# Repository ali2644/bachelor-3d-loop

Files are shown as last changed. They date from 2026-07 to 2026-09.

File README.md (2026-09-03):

# Automated R.E.P.P.R.I.N.T. - 3D-Druck-Qualitätsregelkreis

Dieses Repository automatisiert einen geschlossenen Versuchs- und Optimierungskreislauf für den FFF-3D-Druck. Ein Python-Orchestrator erzeugt aus Prozessparametern ein PrusaSlicer-Profil, überträgt den G-Code per PrusaLink, überwacht den Druck, lässt einen Niryo Ned2 das Bauteil in eine Qualitätsstation einlegen, liest `Ra` und `Rz` eines Mitutoyo SJ-220 aus und speichert Messwerte sowie Kamerabild. Ein separates Optimierer-Framework kann daraus den nächsten Parametersatz bestimmen.

> **Sicherheit:** Die Modi `robot-qs`, `full`, `experiment` und der bestätigte Optimierer-Hardwarelauf bewegen reale Hardware. Vor dem Start Arbeitsräume räumen, Not-Aus erreichbar halten und die mechanische Anordnung prüfen. Roboterbewegungen niemals blind wiederholen.

## Aktueller Stand

Der Stand dieses Übergabepakets basiert auf Branch `feature/optimizer-framework-integration`, Commit `29f11b9`.

| Bereich | Stand |
| --- | --- |
| Slicer, PrusaLink, Robotik, QS und Kamera | Im End-to-End-Orchestrator verbunden; reale Hardware hier nicht erneut getestet |
| Statischer Versuchsplan | Bis 100 Planzeilen, manueller Start-/Endbereich und Plan-Wiederverwendung |
| Optimierer | LHS/Random/Sobol-Warmstart sowie Bayesian, PSO, Differential Evolution, Random und Sobol; Hardwareadapter und persistenter Zustand vorhanden |
| Resume | Für vorgeschlagene, retry-fähige und terminal klassifizierte Läufe vorhanden; ein nach Prozessabbruch als `running` verbliebener Lauf besitzt noch keinen unterstützten CLI-Freigabepfad |
| Installation | Linux-orientiert; Dependency-Dateien sind derzeit unvollständig und werden in der Installationsanleitung erläutert |
| Tests | 129 Tests erfolgreich; ein veralteter Test importiert das nicht mehr vorhandene Modul `optimizer.bayesian_optimizer` |

## System in einem Satz

```text
Parameter -> Profil -> G-Code -> Druck -> Kamera -> Roboter -> Rauheitsmessung -> Speicherung -> nächster Parameter
```

Die Steueranwendung läuft auf dem Hauptrechner. Die FastAPI für SJ-220 und Kamera läuft auf dem Raspberry Pi. Drucker und Roboter werden über das lokale Netz angesprochen; das Messgerät hängt seriell, die Kamera per V4L2 am Raspberry Pi.

## Voraussetzungen in Kürze

- Linux auf Hauptrechner und Raspberry Pi; Python 3.10 oder neuer, mit 3.12.3 verifiziert.
- PrusaSlicer als ausführbare Datei auf dem Hauptrechner.
- Für Hardwarebetrieb: erreichbarer Prusa-Drucker mit PrusaLink, Niryo Ned2, Raspberry Pi 5, Mitutoyo SJ-220 und V4L2-Kamera.
- Auf dem Pi zusätzlich `ffmpeg` und `v4l2-ctl`.

## Schnellstart ohne Hardware

Alle folgenden Befehle werden im Repository-Root ausgeführt, sofern nicht anders angegeben.

```bash
python3.12 -m venv .venv
source .venv/bin/activate
python -m pip install --upgrade pip
python -m pip install -r 3d-automation/requirements.txt
python -m pip install numpy scipy scikit-learn
cd 3d-automation
export PYTHONPATH="$PWD/src"
python -m main --help
python -m optimizer.config config/optimizer_config.example.json --check-input-files
python -m optimizer.warm_start config/optimizer_config.example.json
```

Warum zusätzliche Pakete installiert werden müssen und welche Python-Version tatsächlich ableitbar ist, steht in [Installation](3d-automation/docs/03_installation.md).

Eine neue Simulation benötigt ein neues, noch nicht vorhandenes `paths.output_directory` in der Optimierer-JSON:

```bash
python -m optimizer.framework_runner \
  config/optimizer_config.simulation.json \
  --simulate \
  --new \
  --max-runs 6
```

Existiert das konfigurierte Ausgabeverzeichnis bereits, ist statt `--new` ein passender `--resume`-Aufruf erforderlich. Details: [Bedienung](3d-automation/docs/06_bedienung.md).

## Start mit Hardware - Kurzfassung

1. Auf dem Raspberry Pi die QS-/Kamera-API starten und `/health` sowie `/camera/health` prüfen.
2. Auf dem Hauptrechner `config/end_to_end.env.example` nach `config/end_to_end.env` kopieren, Zugangsdaten eintragen und die Datei in die Shell laden.
3. Zuerst `python -m main --mode preflight` ausführen.
4. Mechanik getrennt mit einem vorhandenen Bauteil prüfen.
5. Erst danach einen Einzelzyklus oder den bewachten Optimierer-Hardwarelauf starten.

```bash
cd 3d-automation
set -a
source config/end_to_end.env
set +a
export PYTHONPATH="$PWD/src"
python -m main --mode preflight
```

Der Optimierer besitzt zusätzliche Sicherheitsgates. Ein neues Experiment wird zunächst nur angelegt und geprüft:

```bash
cp config/optimizer_config.example.json \
  config/optimizer_config.hardware.local.json
# Danach Experimentname, sichere Grenzen und einen neuen Ausgabepfad eintragen.
python -m optimizer.hardware_cli \
  config/optimizer_config.hardware.local.json \
  --new \
  --preflight-only \
  --failure-result penalty
```

Die vorhandene `optimizer_config.example.json` ist ein Strukturbeispiel und keine automatische Freigabe für reale Hardware. Vor dem Aufruf muss die lokale Kopie kontrolliert editiert werden.

## Dokumentation

| Kapitel | Inhalt |
| --- | --- |
| [01 Systemüberblick](3d-automation/docs/01_systemueberblick.md) | Ziel, Geräteverteilung, Daten- und Kontrollfluss |
| [02 Repository und Architektur](3d-automation/docs/02_repository_und_architektur.md) | Verzeichnisse, Module, Klassen, Zustände und Schnittstellen |
| [03 Installation](3d-automation/docs/03_installation.md) | Einrichtung von Hauptrechner und Raspberry Pi |
| [04 Konfiguration](3d-automation/docs/04_konfiguration.md) | Umgebungsvariablen, CLI, JSON und Slicer-Profil |
| [05 Hardware-Setup](3d-automation/docs/05_hardware_setup.md) | Drucker, Roboter, SJ-220, Raspberry Pi, Kamera und QS |
| [06 Bedienung](3d-automation/docs/06_bedienung.md) | Befehle und vollständige Betriebschecklisten |
| [07 Versuche und Daten](3d-automation/docs/07_versuche_und_daten.md) | Pläne, IDs, CSV/JSON, Bilder, Logs und Resume |
| [08 Optimierer](3d-automation/docs/08_optimierer.md) | Warmstart, Strategien, Bayesian Optimization und Zustände |
| [09 Fehlerbehandlung](3d-automation/docs/09_fehlerbehandlung.md) | Diagnose, Retry, Penalty und manuelle Stopps |
| [10 Tests und Entwicklung](3d-automation/docs/10_tests_und_entwicklung.md) | Tests, Simulation, Erweiterung und Debugging |
| [11 API-Referenz](3d-automation/docs/11_api_referenz.md) | QS-/Kamera-Routen und Clientverhalten |
| [12 Übergabe und offene Punkte](3d-automation/docs/12_uebergabe_und_offene_punkte.md) | Reifegrad, Risiken, Schulden und nächste Schritte |

## Verbindliche Quellen

Bei Widersprüchen gilt in dieser Reihenfolge:

1. aktueller Produktionscode und zugehörige Tests,
2. aktuelle Konfigurationsdateien,
3. diese Übergabedokumentation,
4. ältere Meilenstein-Dokumente wie `OPTIMIZER_FRAMEWORK_STEP_*.md`.

Die älteren Schrittdateien bleiben als Entwicklungshistorie erhalten. Mehrere Aussagen darin sind inzwischen überholt; sie sind nicht die aktuelle Bedienungsanleitung.

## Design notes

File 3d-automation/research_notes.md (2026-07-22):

1. downloading and configuring prusaSlicer cli && first use of it 
https://www.accessiblestem.org/fabrication%20lab/prusa-slicer-advanced.html
2. Source of config file 
https://github.com/funkonaut/openSCAD_lessons/blob/main/3D_Printing/profiles/prusa_mini%2B/quality_supports_pla.ini

3. Slicer Manual 
https://manual.slic3r.org/advanced/command-line

4. sending g-codes to printer via network 
https://help.prusa3d.com/article/sending-g-codes-to-printer-via-network-prusa-connect-prusalink-octoprint_196761

5. for g-code understanding 
https://www.cnckitchen.com/blog/g-code-basics-for-3d-printing
https://howtomechatronics.com/tutorials/g-code-explained-list-of-most-important-g-code-commands/

6. Prusa Link API
https://pypi.org/project/PrusaLinkPy/

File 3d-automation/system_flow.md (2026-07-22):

Parameter → config.ini
Prusa CLI → G-Code
Upload via Prusa Link API
Druckstatus polling
FINISHED Signal
Robot fährt Greifsequenz
Übergabe an QS
RS232 Messung
Ergebnis zurück
Optimizer update

-------------------------------------------

Optimizer → Parameter
↓
Printer → Druck starten
↓
WAIT → FINISHED
↓
Robot → Teil entnehmen
↓
QS → messen
↓
Optimizer → neue Parameter
↓
LOOP

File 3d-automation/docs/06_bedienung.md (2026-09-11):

# 06 – Bedienung

Diese Anleitung beschreibt die Bedienung des Systems aus Sicht der Person, die
Versuche plant, startet, überwacht, fortsetzt und die Ergebnisse weitergibt.
Für die Bedienung ist kein Verständnis jeder Python-Klasse erforderlich.

## 1. Die zwei Programmeinstiege

Es gibt zwei getrennte Bedienwege:

| Einstieg | Zweck | Ergebnisverwaltung |
|---|---|---|
| `python -m main` | Preflight, Roboter-QS-Test, einzelner Druck oder vorgegebener CSV-Versuchsplan | ausdrücklich angegebene `--results-csv` |
| `python -m optimizer.hardware_cli` | Optimierer mit Warmstart, BO, PSO, DE, Random oder Sobol | eigener Experimentordner aus der Optimierer-JSON |

`main` und das Optimierer-Framework sollen nicht gleichzeitig auf die Anlage
zugreifen.

## 2. Sicherheits- und Datenregeln

1. Vor Hardwarebefehlen Druckbett, Roboterbereich, Zuführung und Messstation
   prüfen.
2. Es darf immer nur ein steuernder Prozess laufen.
3. Ein neuer Versuch erhält einen neuen Ergebnisnamen beziehungsweise einen
   neuen `output_directory`.
4. Eine begonnene Optimierer-Konfiguration wird nicht verändert. Änderungen an
   STL, Profil, Grenzen, Zielfunktion oder Strategie erfordern ein neues
   Experiment.
5. `--new` bedeutet wirklich neues Experiment. `--resume` öffnet ein
   vorhandenes Experiment.
6. Einen physischen Optimiererlauf niemals ohne vorherigen erfolgreichen
   Preflight starten.
7. Bei einem unklaren Roboter- oder Anlagenzustand zuerst die Anlage prüfen und
   erst danach einen Wiederanlauf bestätigen.

## 3. Einrichtung auf einem neuen Benutzerkonto

### 3.1 Projektstand laden

Im bereits geklonten Repository:

```bash
git fetch origin
git switch feature/optimizer-framework-integration
git pull --ff-only
git status -sb
```

Erwartet wird ein sauberer Arbeitsbaum. Falls der Branch lokal noch nicht
existiert:

```bash
git switch --track origin/feature/optimizer-framework-integration
```

### 3.2 Python-Umgebung

Vom Repository-Ordner `bachelor-3d-loop` aus:

```bash
python3 -m venv .venv
source .venv/bin/activate
python -m pip install --upgrade pip
python -m pip install -r 3d-automation/requirements.txt
cd 3d-automation
```

Vor jedem neuen Terminal:

```bash
cd ~/Projects/bachelor-3d-loop
source .venv/bin/activate
cd 3d-automation
export PYTHONPATH="$PWD/src"
```

Der Hardwarebetrieb ist für den Linux-Laborrechner vorgesehen. Auf einem
Windows-Laptop können Konfiguration, Simulation und viele Tests betrachtet
werden; Robotik, serielle QS-Anbindung und Laborpfade sind dort nicht
betriebsbereit.

### 3.3 Lokale Umgebungsdatei

Einmalig:

```bash
cp config/end_to_end.env.example config/end_to_end.env
chmod 600 config/end_to_end.env
nano config/end_to_end.env
```

Mindestens zu prüfen:

| Variable | Bedeutung |
|---|---|
| `PRINTER_IP` | IP-Adresse des PrusaLink-Druckers |
| `PRUSALINK_API_KEY` | persönlicher beziehungsweise freigegebener API-Key |
| `ROBOT_IP` | IP-Adresse des Niryo-Roboters |
| `QS_BASE_URL` | Basis-URL der QS-API auf dem Raspberry Pi |
| `CAMERA_BASE_URL` | Kamera-API; normalerweise gleich `QS_BASE_URL` |
| `PRUSASLICER_PATH` | lokaler Pfad zur PrusaSlicer-AppImage |
| `REMOTE_GCODE_PATH` | Zielpfad auf dem Drucker |
| `PRINT_POLL_SECONDS` | Abstand zwischen Druckerstatusabfragen |
| `PRINT_START_TIMEOUT_SECONDS` | maximale Zeit bis der neue Druck aktiv ist |
| `PRINT_TIMEOUT_SECONDS` | maximale Druckdauer |
| `MAX_STATUS_ERRORS` | erlaubte aufeinanderfolgende Statusfehler |
| `PART_COOLING_SECONDS` | Abkühlzeit vor der Roboterbewegung |

Die Datei in die aktuelle Shell laden:

```bash
set -a
source config/end_to_end.env
set +a
```

`config/end_to_end.env` enthält Zugangsdaten und wird nicht committed.

### 3.4 Offline-Abnahme

```bash
PYTHONPATH=src python -m unittest discover -s tests -v
```

Alle Tests müssen mit `OK` enden. Die Tests verwenden simulierte Dienste und
starten weder Drucker noch Roboter.

## 4. Eingabedateien auswählen

Vor einem Versuch müssen vier Arten von Eingaben bewusst gewählt werden:

| Eingabe | Beispiel | Regel |
|---|---|---|
| STL-Modell | `data/models/15x15_V2_rounded.stl` | vor jedem neuen Experiment prüfen |
| Slicer-Basisprofil | `config/slicer_profile.ini` | muss ein vollständiges, funktionierendes Profil sein |
| Ergebnisziel für `main` | `data/results/validation_2026-09-08.csv` | neuer Dateiname für neue Reihe |
| Optimierer-Konfiguration | `config/optimizer_config.hardware.json` | enthält zusätzlich Strategie und Experimentordner |

Absolute und relative Pfade in einer Optimierer-JSON sind erlaubt. Relative
Pfade werden relativ zum Ordner der JSON-Datei aufgelöst.

## 5. Bedienung von `main`

### 5.1 Warum `--results-csv` immer angegeben wird

`--results-csv` ist jetzt ein Pflichtargument. Dadurch kann nicht mehr
unbemerkt eine alte Standard-CSV mit einem anderen Spaltenschema verwendet
werden. Eine vorhandene Datei wird beim Programmstart geprüft, also vor Druck
und Roboterbewegung.

Regel:

- neue Versuchsreihe: neuer CSV-Dateiname;
- Fortsetzung derselben Reihe: dieselbe kompatible CSV;
- alte oder anders aufgebaute CSV: nicht überschreiben, sondern neuen Namen
  wählen oder die alte Datei separat archivieren.

Nur das unmittelbar vorherige Programmschema ohne die neue Spalte
`print_time_seconds` wird verlustfrei ergänzt. Andere Fremd- oder Altschemata
werden weiterhin abgelehnt.

### 5.2 Preflight

```bash
PYTHONPATH=src python -m main \
  --mode preflight \
  --stl data/models/15x15_V2_rounded.stl \
  --profile config/slicer_profile.ini \
  --results-csv data/results/preflight_check.csv
```

Der Preflight prüft Dateien und erreichbare Dienste. Er startet keinen Druck
und bewegt den Roboter nicht. Die angegebene Ergebnisdatei wird durch einen
erfolgreichen Preflight nicht beschrieben; sie ist trotzdem ausdrücklich
angegeben, damit jeder `main`-Aufruf dieselbe eindeutige Form hat.

### 5.3 Nur Roboter und QS mit vorhandenem Bauteil

```bash
PYTHONPATH=src python -m main \
  --mode robot-qs \
  --stl data/models/15x15_V2_rounded.stl \
  --profile config/slicer_profile.ini \
  --results-csv data/results/robot_qs_2026-09-08.csv
```

Das Bauteil muss vorher an der eingelernten Position liegen. Es wird nicht
gesliced oder gedruckt. Robotertransport, QS-Messung und Ergebnisaufzeichnung
werden ausgeführt.

### 5.4 Ein vollständiger Zyklus mit Profilwerten

```bash
PYTHONPATH=src python -m main \
  --mode full \
  --stl data/models/15x15_V2_rounded.stl \
  --profile config/slicer_profile.ini \
  --generated-profiles-dir data/generated_profiles \
  --gcode data/gcode/single_cycle.gcode \
  --results-csv data/results/single_cycle_2026-09-08.csv
```

Ohne Parameterargumente werden die sechs Werte aus dem Basisprofil gelesen.

### 5.5 Ein vollständiger Zyklus mit allen Parameterargumenten

```bash
PYTHONPATH=src python -m main \
  --mode full \
  --stl data/models/15x15_V2_rounded.stl \
  --profile config/slicer_profile.ini \
  --generated-profiles-dir data/generated_profiles \
  --gcode data/gcode/single_cycle_all_arguments.gcode \
  --results-csv data/results/single_cycle_all_arguments.csv \
  --top-solid-layers 5 \
  --print-speed 70.0 \
  --extrusion-width 0.42 \
  --extrusion-multiplier 1.10 \
  --temperature 225 \
  --fan-speed 60
```

Diese Parameter gelten nur für einen einzelnen `full`- oder `robot-qs`-Aufruf.
Im Modus `experiment` kommen die Parameter aus dem CSV-Plan; dort werden
Parameterargumente abgelehnt.

### 5.6 Neuen CSV-Versuchsplan erzeugen und ausführen

Das folgende Beispiel erzeugt reproduzierbar einen 100-Zeilen-Plan und führt
die Einträge 1 bis einschließlich 20 aus:

```bash
mkdir -p data/results

RESULTS_CSV="data/results/experiment_$(date +%Y%m%d_%H%M%S).csv"

printf '%s\n' "$RESULTS_CSV" \
  > data/results/active_experiment_results.txt

PYTHONPATH=src python -m main \
  --mode experiment \
  --stl data/models/15x15_V2_rounded.stl \
  --profile config/slicer_profile.ini \
  --generated-profiles-dir data/generated_profiles \
  --gcode data/gcode/experiment.gcode \
  --results-csv "$RESULTS_CSV" \
  --experiment-plan config/experiment_plans/experiment_plan_100.csv \
  --experiment-start-cycle 1 \
  --experiment-cycles 100 \
  --experiment-plan-seed 42
```

`--experiment-cycles` ist die Nummer des letzten Eintrags, nicht die Anzahl ab
dem Start. Beispiel: Start 49 und Ende 100 führen 52 Zyklen aus.

Ohne `--reuse-experiment-plan` wird ein neuer Plan erzeugt. Der vorherige Plan
wird im Archivordner gesichert.

### 5.7 Unterbrochenen CSV-Versuchsplan fortsetzen

```bash
RESULTS_CSV="$(cat data/results/active_experiment_results.txt)"

PYTHONPATH=src python -m main \
  --mode experiment \
  --stl data/models/15x15_V2_rounded.stl \
  --profile config/slicer_profile.ini \
  --generated-profiles-dir data/generated_profiles \
  --gcode data/gcode/experiment.gcode \
  --results-csv "$RESULTS_CSV" \
  --experiment-plan config/experiment_plans/experiment_plan_100.csv \
  --experiment-start-cycle 38 \
  --experiment-cycles 100 \
  --reuse-experiment-plan
```

Beim Fortsetzen darf `--experiment-plan-seed` nicht zusätzlich angegeben
werden. Sonst wäre unklar, ob der bestehende oder ein neuer Plan gemeint ist.

## 5.8 Ergebnisse einer `main`-Versuchsreihe gemeinsam speichern

Für jede neue Versuchsreihe wird ein eigener Ordner angelegt. Darin werden folgende Dateien gespeichert:

- verwendetes STL-Modell,
- verwendetes Slicer-Basisprofil,
- Parameterplan,
- generierte Slicer-Profile,
- erzeugte G-Code-Dateien,
- Kamerabilder,
- Ergebnis-CSV,
- vollständige Terminalausgabe als Logdatei.

### 5.8.1 Neue Versuchsreihe starten

> Dieser Block darf nur für eine neue Versuchsreihe verwendet werden.  
> Für die Fortsetzung einer unterbrochenen Reihe muss der Befehl aus dem nächsten Abschnitt verwendet werden.

Den folgenden Block vollständig kopieren und im Projektordner ausführen:

```bash
set -o pipefail

mkdir -p data/experiments

RUN_DIR="data/experiments/main_$(date +%Y%m%d_%H%M%S_%N)"

mkdir -p "$RUN_DIR"/{input,generated_profiles,gcode,images,logs}

cp data/models/15x15_V2_rounded.stl \
  "$RUN_DIR/input/model.stl"

cp config/slicer_profile.ini \
  "$RUN_DIR/input/base_profile.ini"

printf '%s\n' "$RUN_DIR" \
  > data/experiments/active_main_experiment.txt

CAMERA_DOWNLOAD_DIR="$RUN_DIR/images" \
PYTHONPATH=src python -m main \
  --mode experiment \
  --stl "$RUN_DIR/input/model.stl" \
  --profile "$RUN_DIR/input/base_profile.ini" \
  --generated-profiles-dir "$RUN_DIR/generated_profiles" \
  --gcode "$RUN_DIR/gcode/output.gcode" \
  --results-csv "$RUN_DIR/results.csv" \
  --experiment-plan "$RUN_DIR/experiment_plan_100.csv" \
  --experiment-start-cycle 1 \
  --experiment-cycles 100 \
  --experiment-plan-seed 42 \
  2>&1 | tee "$RUN_DIR/logs/main.log"
```

Der Zeitstempel sorgt dafür, dass jede Versuchsreihe einen neuen eindeutigen Ordner erhält, zum Beispiel:

```text
data/experiments/main_20260907_143215_382019475/
```

Die Datei

```text
data/experiments/active_main_experiment.txt
```

enthält den Pfad der aktuell laufenden Versuchsreihe. Dadurch muss sich der Bediener den erzeugten Zeitstempel nicht merken.

Die Ergebnisse werden folgendermaßen abgelegt:

```text
data/experiments/main_20260907_143215_382019475/
├── input/
│   ├── model.stl
│   └── base_profile.ini
├── experiment_plan_100.csv
├── generated_profiles/
│   ├── cycle_001_profile.ini
│   ├── cycle_002_profile.ini
│   └── ...
├── gcode/
│   ├── cycle_001.gcode
│   ├── cycle_002.gcode
│   └── ...
├── images/
│   ├── <cycle-id>.jpg
│   └── ...
├── logs/
│   └── main.log
└── results.csv
```

Bedeutung der wichtigsten Dateien:

| Datei oder Ordner | Inhalt |
|---|---|
| `input/model.stl` | Kopie des verwendeten Druckmodells |
| `input/base_profile.ini` | Kopie des verwendeten Slicer-Basisprofils |
| `experiment_plan_100.csv` | Parameter aller 100 geplanten Zyklen |
| `generated_profiles/` | Für jeden Zyklus erzeugtes Slicer-Profil |
| `gcode/` | Für jeden Zyklus erzeugter G-Code |
| `images/` | Von der Kamera aufgenommene Bauteilbilder |
| `results.csv` | Ergebnisse und Zustände der ausgeführten Zyklen |
| `logs/main.log` | Vollständige Terminalausgabe der Versuchsreihe |

### 5.8.2 Unterbrochene Versuchsreihe fortsetzen

Beim Fortsetzen darf kein neuer Versuchsordner und kein neuer Parameterplan erzeugt werden.

Zuerst muss bestimmt werden, welcher Zyklus als Nächstes ausgeführt werden soll.

Beispiel:

- Zyklus 37 wurde erfolgreich abgeschlossen.
- Die Fortsetzung beginnt deshalb bei Zyklus 38.
- `--experiment-cycles 100` bedeutet, dass bis einschließlich Zyklus 100 ausgeführt wird.

Den folgenden Block vollständig kopieren und ausführen:

```bash
set -o pipefail

RUN_DIR="$(cat data/experiments/active_main_experiment.txt)"

CAMERA_DOWNLOAD_DIR="$RUN_DIR/images" \
PYTHONPATH=src python -m main \
  --mode experiment \
  --stl "$RUN_DIR/input/model.stl" \
  --profile "$RUN_DIR/input/base_profile.ini" \
  --generated-profiles-dir "$RUN_DIR/generated_profiles" \
  --gcode "$RUN_DIR/gcode/output.gcode" \
  --results-csv "$RUN_DIR/results.csv" \
  --experiment-plan "$RUN_DIR/experiment_plan_100.csv" \
  --experiment-start-cycle 38 \
  --experiment-cycles 100 \
  --reuse-experiment-plan \
  2>&1 | tee -a "$RUN_DIR/logs/main.log"
```

Die Zahl hinter `--experiment-start-cycle` muss durch die Nummer des nächsten auszuführenden Zyklus ersetzt werden.

Beispiele:

| Letzter vollständig abgeschlossener Zyklus | Nächster Startwert |
|---:|---:|
| 10 | `--experiment-start-cycle 11` |
| 37 | `--experiment-start-cycle 38` |
| 60 | `--experiment-start-cycle 61` |
| 99 | `--experiment-start-cycle 100` |

Beim Fortsetzen bewirkt `--reuse-experiment-plan`, dass der vorhandene Parameterplan unverändert geladen wird.

Außerdem werden weiterhin dieselben Ablagen verwendet:

- dieselbe `results.csv`,
- derselbe Bilderordner,
- derselbe G-Code-Ordner,
- derselbe Profilordner,
- dieselbe Logdatei.

`tee -a` hängt die neue Terminalausgabe an die vorhandene Logdatei an. Die vorherige Ausgabe wird dadurch nicht überschrieben.

### 5.8.3 Wichtige Regeln beim Fortsetzen

Beim Fortsetzen dürfen folgende Bestandteile nicht verwendet werden:

```text
$(date ...)
--experiment-plan-seed
```

Ein neuer Zeitstempel würde einen neuen Ordner erzeugen. Ein neuer Seed würde einen neuen Parameterplan erzeugen.

Zum Fortsetzen werden stattdessen immer verwendet:

```text
data/experiments/active_main_experiment.txt
--reuse-experiment-plan
```

### 5.8.4 Aktuellen Versuchsordner anzeigen

```bash
cat data/experiments/active_main_experiment.txt
```

### 5.8.5 Gespeicherte Dateien anzeigen

```bash
RUN_DIR="$(cat data/experiments/active_main_experiment.txt)"

find "$RUN_DIR" -maxdepth 2 -type f | sort
```

### 5.8.6 Hinweis zur Ordneraufteilung

Dieser Ablauf erstellt einen gemeinsamen Ordner für eine vollständige Versuchsreihe.

Die einzelnen Zyklen erhalten darin jeweils:

- ein eigenes generiertes Slicer-Profil,
- eine eigene G-Code-Datei,
- ein eigenes Kamerabild,
- eine eigene Zeile in `results.csv`.

Es wird nicht für jeden einzelnen Zyklus ein separater Hauptordner erstellt.

### 5.9 Alle `main`-Argumente

| Argument | Wirkung |
|---|---|
| `--mode` | `preflight`, `robot-qs`, `full` oder `experiment` |
| `--stl` | verwendetes Modell |
| `--profile` | unverändertes Basisprofil |
| `--generated-profiles-dir` | Ablage der erzeugten Profile |
| `--gcode` | G-Code-Ziel; bei Experimenten wird dessen Ordner verwendet |
| `--results-csv` | Pflichtziel für Zyklusergebnisse |
| `--experiment-plan` | CSV-Datei mit 100 Parametersätzen |
| `--experiment-start-cycle` | erster Planindex, inklusive |
| `--experiment-cycles` | letzter Planindex, inklusive |
| `--reuse-experiment-plan` | vorhandenen Plan beibehalten |
| `--experiment-plan-seed` | Seed für einen reproduzierbaren neuen Plan |
| sechs Parameterargumente | Einzelzykluswerte; im Experimentmodus verboten |

## 6. Optimierer-Konfiguration

### 6.1 Grundstruktur

```json
{
  "schema_version": 1,
  "experiment_name": "surface_roughness_example_001",
  "total_runs": 100,
  "seed": 42,
  "objective": "Ra_um + 0.1 * print_time_minutes",
  "warm_start": {
    "method": "lhs",
    "sample_count": 10
  },
  "strategy": {
    "name": "bayesian",
    "options": {
      "acquisition": "ei",
      "candidate_count": 4096,
      "n_restarts_optimizer": 5
    }
  },
  "parameters": [
    {"name": "print_speed", "lower": 50, "upper": 90},
    {"name": "extrusion_width", "lower": 0.38, "upper": 0.50},
    {"name": "extrusion_multiplier", "lower": 1.05, "upper": 1.20},
    {"name": "temperature", "lower": 215, "upper": 235},
    {"name": "fan_speed", "lower": 30, "upper": 80}
  ],
  "fixed_parameters": {
    "top_solid_layers": 5
  },
  "paths": {
    "stl": "../data/models/15x15_V2_rounded.stl",
    "base_profile": "slicer_profile.ini",
    "output_directory": "../data/optimization_runs/example_001",
    "history_csvs": []
  }
}
```

### 6.2 Felder

| Feld | Bedeutung |
|---|---|
| `schema_version` | Formatversion; aktuell `1` |
| `experiment_name` | eindeutiger lesbarer Name |
| `total_runs` | Zahl abgeschlossener Parametersätze, nicht physischer Versuche |
| `seed` | reproduzierbare Zufallsfolge |
| `objective` | zu minimierende Messgröße oder Rechenformel |
| `warm_start.method` | `lhs`, `random` oder `sobol` |
| `warm_start.sample_count` | Zahl der Startpunkte; bei Batchstrategien zugleich Batchgröße |
| `strategy.name` | `bayesian`, `pso`, `differential_evolution`, `random` oder `sobol` |
| `strategy.options` | Optionen der gewählten Strategie |
| `parameters` | variable Parameter und frei gewählte Grenzen |
| `fixed_parameters` | nicht optimierte Parameter |
| `paths.output_directory` | ausschließlich für dieses Experiment |
| `paths.history_csvs` | reserviert; aktuell immer `[]`, Import noch nicht implementiert |

Jeder der sechs Prozessparameter muss genau einmal vorkommen: entweder variabel
in `parameters` oder fest in `fixed_parameters`.

### 6.3 Frei wählbare Grenzen und Top-Layer

`top_solid_layers` bleibt für den aktuellen Versuch fest auf 5:

```json
"fixed_parameters": {"top_solid_layers": 5}
```

Für einen späteren Versuch kann es stattdessen optimiert werden:

```json
"parameters": [
  {"name": "top_solid_layers", "lower": 3, "upper": 7}
],
"fixed_parameters": {
  "print_speed": 70,
  "extrusion_width": 0.42,
  "extrusion_multiplier": 1.10,
  "temperature": 225,
  "fan_speed": 60
}
```

Formale Mindestregeln: Geschwindigkeiten, Breiten und Multiplikator sind größer
als null; Temperatur und Top-Layer sind nichtnegative ganze Zahlen; Lüfter ist
eine ganze Zahl von 0 bis 100; bei Variablen gilt `lower < upper`. Formal
gültige extreme Grenzen sind nicht automatisch physikalisch sicher.

### 6.4 Zielfunktion

`objective` ist eine sichere arithmetische Formel. Verfügbare Größen:

| Name | Einheit | Bedeutung |
|---|---:|---|
| `Ra_um` | µm | gemessener Ra-Wert |
| `Rz_um` | µm | gemessener Rz-Wert |
| `print_time` | s | beobachtete Druckzeit |
| `print_time_seconds` | s | eindeutiger Alias für `print_time` |
| `print_time_minutes` | min | Druckzeit geteilt durch 60 |

Erlaubt sind Zahlen, Klammern und `+`, `-`, `*`, `/`, `**`. Nicht erlaubt
sind Funktionsaufrufe, Vergleiche, Imports oder beliebige Python-Ausdrücke.

Beispiele:

```json
"objective": "Ra_um"
```

```json
"objective": "Ra_um + 0.1 * print_time_minutes"
```

```json
"objective": "5 + print_time_minutes * Ra_um + Rz_um"
```

Die Gewichte bestimmen die fachliche Bedeutung. Sekundenwerte sind numerisch
viel größer als Rauheitswerte; deshalb ist meist `print_time_minutes` oder ein
kleiner Faktor sinnvoll.

`print_time` wird ab dem Warten auf den nach dem Upload gestarteten Druck bis
zum beobachteten Zustand `FINISHED` gemessen. Slicing, Kamera, Abkühlen,
Roboterbewegung und QS-Messung gehören nicht dazu. `duration_seconds` in
`hardware_cycles.csv` ist dagegen die Gesamtdauer des gesamten Zyklus.

Bei einem Parametersatz, der zweimal fehlschlägt, wird die Formel nicht mit
erfundenen Ra-, Rz- oder Zeitwerten ausgewertet. Im Modus `penalty` wird direkt
`objective_value = 100.0` gespeichert. Deshalb muss 100 auf der Skala der
gewählten Formel tatsächlich ein schlechter Wert sein. Andernfalls ist für
dieses Experiment `ignore` die fachlich sichere Wahl.

### 6.5 Strategiebedingungen

- Bayesian: nach dem Warmstart jeweils ein neuer Vorschlag.
- PSO, DE, Random und Sobol: Vorschläge in vollständigen Batches der Größe
  `warm_start.sample_count`.
- Bei den Batchstrategien muss `total_runs - sample_count` ohne Rest durch
  `sample_count` teilbar sein.
- PSO benötigt mindestens 2 Startpunkte, DE mindestens 4.

## 7. Optimierer offline prüfen

### 7.1 JSON und Eingabedateien prüfen

```bash
PYTHONPATH=src python -m optimizer.config \
  config/optimizer_config.hardware.json \
  --check-input-files
```

Ohne `--check-input-files` wird nur Struktur und Inhalt der JSON geprüft.

### 7.2 Warmstartpunkte anzeigen

```bash
PYTHONPATH=src python -m optimizer.warm_start \
  config/optimizer_config.hardware.json
```

Das erzeugt keine Hardwarebewegung und legt noch kein Experiment an.

### 7.3 Neue Simulation

Vorher in der Simulations-JSON einen noch nicht vorhandenen
`output_directory` wählen:

```bash
PYTHONPATH=src python -m optimizer.framework_runner \
  config/optimizer_config.simulation.json \
  --new \
  --simulate \
  --max-runs 3
```

### 7.4 Simulation fortsetzen

```bash
PYTHONPATH=src python -m optimizer.framework_runner \
  config/optimizer_config.simulation.json \
  --resume \
  --simulate \
  --from-run 4 \
  --max-runs 2
```

`--retry-failed` wird nur verwendet, wenn der gespeicherte nächste Run den
Status `retryable_failed` besitzt:

```bash
PYTHONPATH=src python -m optimizer.framework_runner \
  config/optimizer_config.simulation.json \
  --resume \
  --simulate \
  --from-run 4 \
  --retry-failed \
  --max-runs 1
```

## 8. Neues Optimierer-Hardwareexperiment

### 8.1 Konfiguration kopieren

```bash
cp config/optimizer_config.example.json \
  config/optimizer_config.hardware.json
nano config/optimizer_config.hardware.json
```

Prüfen:

- neuer `experiment_name`;
- neuer, noch nicht vorhandener `output_directory`;
- richtige STL;
- richtiges Basisprofil;
- gewünschte Grenzen und feste Parameter;
- gewünschte Zielfunktion;
- Strategie, Warmstart und Gesamtzahl;
- `history_csvs` ist `[]`.

### 8.2 Fehlerergebnis einmalig wählen und Preflight ausführen

Penalty soll in den Optimierer eingehen:

```bash
PYTHONPATH=src python -m optimizer.hardware_cli \
  config/optimizer_config.hardware.json \
  --new \
  --failure-result penalty \
  --preflight-only
```

Fehlerhafter Parametersatz soll nicht als Optimiererbeobachtung eingehen:

```bash
PYTHONPATH=src python -m optimizer.hardware_cli \
  config/optimizer_config.hardware.json \
  --new \
  --failure-result ignore \
  --preflight-only
```

Die Wahl wird in `run_state.json` gespeichert und darf innerhalb des
Experiments nicht gewechselt werden.

### 8.3 Genau einen Parametersatz ausführen

```bash
PYTHONPATH=src python -m optimizer.hardware_cli \
  config/optimizer_config.hardware.json \
  --resume \
  --from-run 1 \
  --max-runs 1 \
  --confirm-hardware
```

Ohne `--max-runs` ist 1 der Standard. Ohne `--confirm-hardware` wird kein
physischer Optimiererzyklus gestartet.

### 8.4 Mehrere Parametersätze automatisch ausführen

Beispiel für 12 abgeschlossene Parametersätze:

```bash
PYTHONPATH=src python -m optimizer.hardware_cli \
  config/optimizer_config.hardware.json \
  --resume \
  --from-run 1 \
  --max-runs 12 \
  --automatic-retry \
  --confirm-hardware
```

`--max-runs 12` zählt Parametersätze, nicht physische Drucke. Ein automatisch
wiederholter Fehlversuch kann also zusätzliche physische Zyklen verursachen.
Vor jedem Versuch wird ein Preflight-Nachweis erzeugt oder geprüft.

## 9. Fehler- und Wiederanlaufregeln

### 9.1 Normaler vergleichbarer Fehler

Bei einem vergleichbaren Druck-/Status- oder Messfehler:

1. Versuch 1 wird mit Fehler archiviert.
2. Mit `--automatic-retry` werden dieselben Parameter genau einmal wiederholt.
3. Bei Erfolg werden echte Werte gespeichert.
4. Bei erneutem Fehler wird der Parametersatz als `penalty` oder
   `ignored_failure` abgeschlossen.
5. Ein dritter automatischer Versuch ist nicht erlaubt.

Ohne automatischen Modus wird der erste Fehler bewusst sichtbar. Danach:

```bash
PYTHONPATH=src python -m optimizer.hardware_cli \
  config/optimizer_config.hardware.json \
  --resume \
  --from-run X \
  --retry-failed \
  --preflight-only
```

Nach erfolgreichem Preflight:

```bash
PYTHONPATH=src python -m optimizer.hardware_cli \
  config/optimizer_config.hardware.json \
  --resume \
  --from-run X \
  --max-runs 1 \
  --confirm-hardware
```

### 9.2 Preflight-Fehler

Ein Preflight-Fehler verbraucht keinen physischen Versuch. Ursache beheben und
denselben Run erneut preflighten:

```bash
PYTHONPATH=src python -m optimizer.hardware_cli \
  config/optimizer_config.hardware.json \
  --resume \
  --from-run X \
  --retry-failed \
  --preflight-only
```

### 9.3 Roboterfehler oder unklarer Anlagenzustand

Diese Fälle stoppen ohne Optimiererbeobachtung. Erst Anlage und Teil prüfen,
dann denselben Run vorbereiten:

```bash
PYTHONPATH=src python -m optimizer.hardware_cli \
  config/optimizer_config.hardware.json \
  --resume \
  --from-run X \
  --resume-after-manual-intervention \
  --preflight-only
```

Nach dem Preflight normal mit `--confirm-hardware` starten.

### 9.4 Programmabsturz mit Runstatus `running`

Zuerst sicherstellen, dass kein alter Python-Prozess, Druckauftrag oder
Roboterbefehl mehr aktiv ist. Anlage manuell prüfen. Erst dann:

```bash
PYTHONPATH=src python -m optimizer.hardware_cli \
  config/optimizer_config.hardware.json \
  --resume \
  --from-run X \
  --resume-interrupted-run \
  --preflight-only
```

Der unterbrochene Zustand wird archiviert und derselbe Parametersatz als neuer
manuell bestätigter Versuch vorbereitet.

### 9.5 Drei fehlerhafte Parametersätze hintereinander

Nach drei Parametersätzen, die jeweils nach zwei vergleichbaren Versuchen ohne
Messung abgeschlossen wurden, stoppt der Dauerlauf. Nach Ursachenprüfung wird
der gespeicherte nächste Run bestätigt:

```bash
PYTHONPATH=src python -m optimizer.hardware_cli \
  config/optimizer_config.hardware.json \
  --resume \
  --from-run X \
  --acknowledge-failure-streak \
  --preflight-only
```

`--acknowledge-penalty-streak` ist ein kompatibler alter Name für dasselbe
Argument. Die Grenze zählt auch im Modus `ignore`.

### 9.6 Typische Fehlermeldungen

| Meldung | Bedeutung | Reaktion |
|---|---|---|
| output directory already exists | `--new` auf vorhandenen Ordner | `--resume` verwenden oder neuen Ordner konfigurieren |
| supplied configuration differs | JSON nach Start verändert | ursprüngliche JSON verwenden oder neues Experiment starten |
| safe resume point is run X | falsches `--from-run` | genau X verwenden |
| preflight receipt is missing | Versuch nicht freigeprüft | `--preflight-only` ausführen |
| existing cycle CSV has a different schema | `main`-CSV stammt aus anderer Version | neue Ergebnisdatei wählen |
| status `running` | Prozess wurde möglicherweise unterbrochen | Anlage prüfen, dann `--resume-interrupted-run` |
| requires manual intervention | unsicherer Hardwarezustand | manuell prüfen, dann manueller Resume |

## 10. Was gespeichert wird

Ein Optimiererexperiment besitzt diese Struktur:

```text
output_directory/
├── config_snapshot.json
├── run_state.json
├── results.csv
├── hardware_cycles.csv
├── runs/
├── attempt_history/
├── optimizer_state/
├── generated_profiles/
├── gcode/
├── images/
└── logs/
```

| Ort | Inhalt |
|---|---|
| `config_snapshot.json` | unveränderter Konfigurationsnachweis mit aufgelösten Pfaden |
| `run_state.json` | Gesamtfortschritt, sicherer nächster Run, Fehlerfolge und Fehlerergebnismodus |
| `runs/run_XXXX.json` | verbindlicher aktueller Zustand eines Parametersatzes |
| `attempt_history/` | frühere Fehl- oder Wiederanlaufversuche unverändert archiviert |
| `results.csv` | eine lesbare Zeile je abgeschlossenem Parametersatz |
| `hardware_cycles.csv` | jeder tatsächlich vom Orchestrator aufgezeichnete Hardwarezyklus |
| `optimizer_state/` | Strategie-Checkpoint und kompletter vorgeschlagener Batch |
| `generated_profiles/` | Profil je Run und Versuch |
| `gcode/` | G-Code je Run und Versuch |
| `images/` | Kamerabild je Hardwarezyklus |
| `logs/optimizer_hardware.log` | Ablauf- und Fehlermeldungen |
| `logs/preflight_*.json` | Preflight-Nachweis je Run und Versuch |

`results.csv` enthält unter anderem `objective_value`, echte `Ra_um` und
`Rz_um`, `print_time_seconds`, `observation_kind`, Penalty-/Ignore-Kennzeichen,
Parameter, Fehler und `cycle_id`.

Die Abschlussausgabe des Hardware-CLI zeigt unter `last_completed_result`
zusätzlich das letzte Zielergebnis, Ra, Rz und `print_time_seconds`. Bei einem
Batch stehen alle Ergebnisse weiterhin vollständig in `results.csv`.

Nicht gespeichert werden API-Keys aus der Umgebung. Der reale mechanische
Zustand der Anlage kann nicht vollständig aus Dateien rekonstruiert werden und
muss nach einem Abbruch immer vor Ort geprüft werden.

## 11. PSO- und DE-Zustand

Ja, beide Zustände werden gespeichert. Vor der ersten physischen Ausführung
eines neuen Batches entsteht ein unveränderlicher JSON-Checkpoint unter:

```text
output_directory/optimizer_state/
```

PSO speichert insbesondere:

- Partikel-IDs, Positionen und Geschwindigkeiten;
- persönliche Bestpositionen und Fitnesswerte;
- globale Bestposition und globalen Bestwert;
- Zufallszustand;
- alle Vorschläge des aktuellen Batches.

Differential Evolution speichert insbesondere:

- Individuen/Population und Fitnesswerte;
- Trial-Population;
- Zufallszustand;
- alle Vorschläge des aktuellen Batches.

Wenn der Prozess beim X-ten Kandidaten eines Batches stoppt, werden bereits
abgeschlossene Kandidaten nicht erneut gedruckt. Der gespeicherte Batch wird
geladen und beim noch offenen X-ten Run fortgesetzt.

Kontrolle:

```bash
ls -lt data/optimization_runs/EXPERIMENT/optimizer_state
python -m json.tool \
  data/optimization_runs/EXPERIMENT/optimizer_state/DATEINAME.json
```

## 12. Zustand und Ergebnisse kontrollieren

Gesamtzustand:

```bash
python -m json.tool \
  data/optimization_runs/EXPERIMENT/run_state.json
```

Einzelner Parametersatz:

```bash
python -m json.tool \
  data/optimization_runs/EXPERIMENT/runs/run_0001.json
```

Letzte Ergebnisse:

```bash
tail -n 5 data/optimization_runs/EXPERIMENT/results.csv
tail -n 5 data/optimization_runs/EXPERIMENT/hardware_cycles.csv
```

Letzte Logmeldungen:

```bash
tail -n 100 \
  data/optimization_runs/EXPERIMENT/logs/optimizer_hardware.log
```

## 13. Daten an einen anderen Rechner übergeben

Der vollständige Experimentordner ist die Übergabeeinheit:

```bash
cd data/optimization_runs
zip -r EXPERIMENT.zip EXPERIMENT
```

Die ZIP-Datei kann per freigegebenem Netzlaufwerk, `scp` oder USB-Datenträger
übergeben werden. Für eine reine Auswertung reichen oft `results.csv`,
`hardware_cycles.csv` und `images/`; für eine vollständige Reproduzierbarkeit
sollte immer der ganze Experimentordner übertragen werden.

## 14. Argument- und Fallabdeckung

Die automatisierten Tests decken alle Bedienargumente und Zustandsübergänge
ohne echte Hardware ab. Zusätzlich müssen Hardwarefälle kontrolliert vor Ort
abgenommen werden.

| Fall | Offline-Test | Reale Abnahme |
|---|---|---|
| alle `main`-Pfade und Einzelparameter | `tests/test_main.py` | Preflight, robot-qs, full |
| neue/fortgesetzte CSV-Reihe | `tests/test_main.py` | je ein kontrollierter Lauf |
| LHS, Random, Sobol | `tests/test_warm_start.py` | Warmstartausgabe prüfen |
| BO, PSO, DE, Random, Sobol | `tests/test_framework_runner.py` | mindestens gewählte Produktivstrategie |
| `--new`, `--resume`, `--from-run`, `--max-runs` | Framework-/Hardware-CLI-Tests | Start und Fortsetzung |
| automatischer Retry, Penalty und Ignore | Hardware-CLI- und Runner-Tests | provozierbarer Messfehler nur unter Aufsicht |
| Preflight-Fehler | `tests/test_hardware_cli.py` | Verbindung vor Druck trennen, falls freigegeben |
| manueller Stopp | `tests/test_hardware_cli.py` | nur bei echtem Fehler anwenden |
| unterbrochener Prozess | `tests/test_hardware_cli.py` | nicht absichtlich bei Bewegung provozieren |
| drei Fehlerparameter hintereinander | `tests/test_framework_runner.py` | Simulation genügt; nicht absichtlich Hardware belasten |
| Formel und Druckzeit | `tests/test_objective.py`, Runner-/Recorder-Tests | einen erfolgreichen Druckwert prüfen |
| inkompatible Ergebnis-CSV | `tests/test_csv_cycle_recorder.py` | keine physische Provokation nötig |

Vollständige Offline-Abnahme:

```bash
PYTHONPATH=src python -m unittest discover -s tests -v
```

Weiter: [07 – Versuche und Daten](07_versuche_und_daten.md)

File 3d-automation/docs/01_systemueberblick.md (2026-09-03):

# 01 – Systemüberblick

## Zweck und Abgrenzung

Automated R.E.P.P.R.I.N.T. untersucht, wie sich Prozessparameter eines FFF-Drucks auf die Oberflächenrauheit auswirken. Das System erzeugt Testkörper, transportiert sie automatisiert zu einer Qualitätsstation und erfasst dort `Ra` und `Rz`. Ein Optimierer kann den Messwert `Ra_um` anschließend als Zielfunktion verwenden und den nächsten Parametersatz vorschlagen.

Der aktuelle Code automatisiert diesen Kreis technisch. Eine wissenschaftliche Bewertung der Druckqualität, eine Modellvalidierung und ein Vergleich verschiedener Regressionsmodelle sind nicht Bestandteil des implementierten Laufzeitpfads. Auch eine Bildauswertung ist nicht implementiert; die Kamera dokumentiert nur den Zustand des Druckteils.

## Verteilung auf die Geräte

| Ort | Software | Angeschlossene beziehungsweise angesprochene Hardware |
| --- | --- | --- |
| Hauptrechner | `main.py`, `PrintOrchestrator`, Slicer-, Drucker-, Roboter- und API-Clients, Versuchsplan, Ergebnis-CSV, Optimierer | Prusa-Drucker und Niryo Ned2 über LAN; Raspberry Pi über HTTP |
| Raspberry Pi 5 | FastAPI-Anwendung `qs.api`, `SJ220Service`, Kamera-Funktionen aus `camera_ctrl` | Mitutoyo SJ-220 an `/dev/ttyUSB0`; Kamera standardmäßig an `/dev/video0` |
| Prusa MINI/MINI+ | PrusaLink und Drucker-Firmware | USB-Datenträger des Druckers, Druckmechanik |
| Niryo Ned2 | Roboter-Firmware | Greifer und mechanische Übergabe zwischen Drucker und QS-Station |
| QS-Station | Mechanik plus SJ-220 | Taster, Hebel und Bauteilaufnahme |

## Gesamtarchitektur

```mermaid
flowchart TD
    O["Optimierer oder Versuchsplan"] --> M["Hauptrechner: Orchestrator"]
    M --> S["PrusaSlicer"]
    M --> P["PrusaLink / Prusa MINI"]
    M --> R["Niryo Ned2"]
    M --> Q["Raspberry Pi: QS-API"]
    Q --> J["Mitutoyo SJ-220"]
    Q --> C["V4L2-Kamera"]
    M --> D["CSV, JSON, G-Code, Bilder und Logs"]
    D --> O
```

Die Kommunikation ist nicht ereignisgetrieben. Der Hauptrechner ruft alle Schritte synchron auf und wartet auf das jeweilige Ergebnis:

- PrusaLink: HTTP mit `X-Api-Key`.
- QS und Kamera: HTTP/JSON ohne im Repository implementierte Authentifizierung.
- Roboter: PyNiryo über die konfigurierte Roboter-IP.
- SJ-220: serielle Kommandos über den Raspberry Pi.
- Kamera: `v4l2-ctl` und `ffmpeg` als lokale Prozesse auf dem Raspberry Pi.

## Ablauf eines vollständigen Zyklus

Die Reihenfolge folgt `PrintOrchestrator._run_cycle()` in `src/orchestrator.py`, aufgerufen über die beiden öffentlichen Zyklusmethoden. Sie weicht von älteren Konzepttexten ab: Das Kamerabild entsteht nach dem Druck und **vor** Abkühlung, Robotertransport und Messung.

```mermaid
sequenceDiagram
    participant A as Hauptrechner
    participant P as Drucker
    participant C as Pi/Kamera
    participant R as Roboter
    participant Q as Pi/SJ-220
    A->>A: Profil erzeugen und slicen
    A->>P: G-Code hochladen und Druck starten
    loop Statusabfrage
        A->>P: /api/v1/status
    end
    P-->>A: FINISHED
    A->>C: Bild mit Cycle-ID aufnehmen
    A->>A: Abkühlzeit warten
    A->>R: Teil entnehmen und in QS einlegen
    A->>Q: Rauheit messen
    Q-->>A: Ra und Rz
    A->>R: QS zurücksetzen und Teil verschieben
    A->>A: Ergebnis speichern
```

Die internen Stufen heißen:

1. `preflight`
2. `slicing`
3. `uploading`
4. `starting_print`
5. `waiting_for_print`
6. `camera_capture`
7. `cooling`
8. `robot_handling`
9. `measuring`
10. `recording`
11. `completed`

Ein `robot-qs`-Zyklus überspringt Slicing, Drucker, Kamera und Abkühlzeit. Er erwartet bereits ein geeignetes Bauteil im Druckerbereich. Der Modus `preflight` bewegt keine Hardware; beim Programmeinstieg wird davor jedoch ein abgeleitetes Slicer-Profil erzeugt.

## Zwei Steuerpfade

### Statischer Versuchsplan

`python -m main --mode experiment` liest genau 100 validierte Parametersätze aus einer CSV. Ohne `--reuse-experiment-plan` wird vor dem Lauf ein neuer Latin-Hypercube-Plan erzeugt und eine vorhandene Plandatei archiviert. Der Benutzer wählt über Start- und Endnummer den auszuführenden Bereich. Die Wiederaufnahme ist manuell und nicht aus der Ergebnis-CSV abgeleitet.

### Adaptiver Optimierer

`optimizer.hardware_cli` verwendet `ExperimentStore`. Jeder Vorschlag und jeder Zustandswechsel wird vor beziehungsweise nach dem physischen Schritt atomar gespeichert. Nach dem Warmstart erzeugt die konfigurierte Strategie neue Vorschläge aus den verwertbaren Beobachtungen. `optimizer.framework_runner` nutzt denselben Zustandsmechanismus mit einem deterministischen Simulator statt Hardware.

## Daten- und Kontrollfluss

| Eingabe | Verarbeitung | Ergebnis |
| --- | --- | --- |
| STL und Basisprofil | `SlicerProfileGenerator` ersetzt sechs relevante Slicer-Werte | zyklusspezifisches INI-Profil |
| INI-Profil und STL | `SlicerService` ruft PrusaSlicer auf | G-Code/BG-Code-Pfad |
| G-Code | `PrusaLinkService` lädt hoch und beobachtet den Druckstatus | Start-/Endstatus |
| Cycle-ID | `CameraClient` stößt Aufnahme an und lädt sie herunter | JPEG auf Hauptrechner und Pi |
| Roboterpositionen | `RobotService` führt eine feste Bewegungsfolge aus | Teil unter dem Taster |
| HTTP-Messauftrag | `SJ220Service` führt das serielle Protokoll aus | `Ra_um`, `Rz_um` |
| Ergebnis | `CsvCycleRecorder` oder `ExperimentStore` | CSV/JSON, Optimiererbeobachtung |

Die statische und die adaptive Ausführung benutzen denselben `PrintOrchestrator`. Sie unterscheiden sich vor allem darin, wie Parameter vorgeschlagen und Ergebnisse persistiert werden.

## Fehler, Wiederholung und Abbruch

```mermaid
flowchart TD
    A["Schritt ausführen"] --> B{"Erfolgreich?"}
    B -- Ja --> C["Ergebnis speichern"]
    B -- Nein --> D{"Messaufruf im Orchestrator?"}
    D -- Ja --> E["Ein zweiter HTTP-Messaufruf"]
    E --> F{"Erfolgreich?"}
    F -- Ja --> C
    F -- Nein --> G["Ra=Rz=100 im Einzelzyklus"]
    D -- Nein --> H["Fehler mit Stufe zurückgeben"]
    H --> I{"Hardwareadapter klassifiziert retry-fähig?"}
    I -- Ja --> J["Optional gleicher Satz einmal erneut"]
    I -- Nein --> K["Stopp bis manueller Eingriff"]
    J --> L{"Zweiter Versuch erfolgreich?"}
    L -- Ja --> C
    L -- Nein --> M["Penalty 100 oder Ignore"]
```

Wichtige Grenzen dieser Logik:

- Der Einzelzyklus behandelt zwei fehlgeschlagene QS-HTTP-Aufrufe als abgeschlossenes Ergebnis mit `Ra=Rz=100`; die nachgelagerte Roboterbewegung wird trotzdem ausgeführt.
- Das SJ-220 führt beim Gerätefehler `007` intern bereits eine zusätzliche Messbewegung aus und meldet danach weiterhin einen Fehler. Zusammen mit dem zweiten HTTP-Aufruf des Orchestrators können daher mehr als zwei physische Messbewegungen entstehen.
- Im Optimierer-Hardwareadapter gelten Fehler in `waiting_for_print` oder `measuring` als physisch verbrauchte, retry-fähige Versuche. Zwei Fehlschläge werden je nach Experimententscheidung als Penalty `100` oder als ignorierte Beobachtung gespeichert.
- Upload-, Kamera-, Roboter-, Recording- und unbekannte Fehler erfordern einen manuellen Stopp. Nach drei aufeinanderfolgenden endgültig fehlgeschlagenen Parametersätzen wird zusätzlich eine Sicherheitsquittierung verlangt.

Die vollständige Matrix steht in [09 – Fehlerbehandlung](09_fehlerbehandlung.md).

## Verifizierungsstatus

| Aussage | Status |
| --- | --- |
| Programmstruktur, Parameterfluss und Fehlerklassifikation | Im Code nachvollzogen |
| CLI-Parser, Konfigurationsprüfung, Warmstart, Simulation | In der bereitgestellten Umgebung ausgeführt |
| Unit-/Integrationstests | 129 erfolgreich, 1 veralteter Importfehler |
| Echte Druck-, Roboter-, Kamera- und Messbewegung | In dieser Dokumentationsrunde nicht ausgeführt |
| Physische Positionen und mechanische Toleranzen | Aus Code abgeleitet; vor Ort erneut zu validieren |

Weiter: [02 – Repository und Architektur](02_repository_und_architektur.md)

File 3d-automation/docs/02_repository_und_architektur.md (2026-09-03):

# 02 – Repository und Architektur

## Relevante Struktur

```text
bachelor-3d-loop/
├── README.md
├── requirements.txt                 # ältere Root-Abhängigkeitsliste
└── 3d-automation/
    ├── config/                      # Env-Beispiel, Slicer- und Optimierer-Konfigurationen
    ├── data/                        # STL, Pläne und vorhandene Laufartefakte
    ├── docs/                        # Übergabe- und historische Meilenstein-Dokumentation
    ├── scripts/                     # Windows-Setup-Skript
    ├── src/                         # Anwendungscode
    ├── tests/                       # unittest-Testmodule
    └── requirements.txt             # Laufzeitabhängigkeiten, derzeit unvollständig
```

Generierte Verzeichnisse wie `__pycache__`, `.venv`, `data/camera_images`, G-Code und Optimierungsläufe sind keine Quelle für die Architektur. Sie dürfen für Diagnosezwecke wichtig sein, sollen aber nicht manuell als Programmzustand editiert werden.

## Einstiegspunkte

Alle Modulaufrufe erfolgen aus `3d-automation/` mit `PYTHONPATH="$PWD/src"`.

| Einstieg | Zweck | Quellcode |
| --- | --- | --- |
| `python -m main` | Preflight, Robot-QS, Einzelzyklus, statischer Versuchsplan | `src/main.py:main` |
| `python -m optimizer.config` | Optimierer-JSON validieren und anzeigen | `src/optimizer/config.py:main` |
| `python -m optimizer.warm_start` | deterministischen Warmstart anzeigen | `src/optimizer/warm_start.py:main` |
| `python -m optimizer.framework_runner` | hardwarefreie Optimierersimulation | `src/optimizer/framework_runner.py:main` |
| `python -m optimizer.hardware_cli` | sicherheitsbegrenzter Optimierer-Hardwarelauf | `src/optimizer/hardware_cli.py:main` |
| `python -m qs.api` | nicht als eigener CLI-Start implementiert; Server wird mit Uvicorn gestartet | `src/qs/api.py:app` |
| `python -m qs.run_sj220` | direkte SJ-220-Messung auf dem Pi | `src/qs/run_sj220.py` |
| – | Für `camera.camera_ctrl` existiert kein eigener CLI-Einstieg; Aufnahmen erfolgen über die API | `src/camera/camera_ctrl.py:capture_still` |
| `python -m robot.robot_service` | direkte Roboterdiagnose; bewegt reale Hardware | `src/robot/robot_service.py` |

## Module und Verantwortlichkeiten

### Orchestrierung und Parameter

| Datei | Zentrale Typen/Funktionen | Verantwortung |
| --- | --- | --- |
| `src/main.py` | `parse_arguments`, `build_orchestrator`, `main` | CLI, Env-Auswertung, Objekterzeugung, Moduswahl |
| `src/orchestrator.py` | `CycleRequest`, `CycleResult`, `CycleStage`, `run_single_print_cycle`, `run_handling_and_measurement_cycle` | genau einen begrenzten Prozesszyklus ausführen |
| `src/printer/print_parameters.py` | `PrintParameters`, `SlicerProfileGenerator.generate` | Parameter validieren und Basisprofil ableiten |
| `src/printer/slicer_service.py` | `SlicerService.send_stl_to_slicer` | PrusaSlicer-Prozess mit Timeout starten |
| `src/printer/prusalink_service.py` | `PrusaLinkService` | Upload, Start und Statusüberwachung per HTTP |

### Hardware und QS

| Datei | Zentrale Typen/Funktionen | Verantwortung |
| --- | --- | --- |
| `src/robot/robot_service.py` | `RobotService`, `prepare_part_for_measurement`, `complete_part_handling_after_measurement` | feste Greif-, Transfer- und QS-Bewegungen |
| `src/robot/robot_positions.py` | benannte `RobotPosition`-Konstanten | sechsachsige Gelenkpositionen und Zwecktexte |
| `src/qs/api.py` | FastAPI-`app` und Routenfunktionen | HTTP-Fassade für Messung und Kamera |
| `src/qs/sj220_service.py` | `SJ220Service` | serielles Protokoll, Statusabfrage, Messwertlesen |
| `src/qs/sj220_models.py` | Status- und Ergebnisdatentypen | Geräteantworten typisieren |
| `src/qs/sj220_exceptions.py` | SJ-spezifische Exceptions | Fehler auf API-Statuscodes abbildbar machen |
| `src/qs/qs_api_client.py` | `QualityStationClient` | Health- und Mess-HTTP-Aufrufe vom Hauptrechner |
| `src/camera/camera_ctrl.py` | `capture_still`, `show_live` | V4L2-Steuerung, ffmpeg-Aufnahme, Livebild |
| `src/camera/camera_client.py` | `CameraClient` | Pi-Aufnahme anstoßen und JPEG herunterladen |

### Versuchsplan, Ergebnisse und Optimierer

| Datei | Zentrale Typen/Funktionen | Verantwortung |
| --- | --- | --- |
| `src/experiments/experiment_plan.py` | `ExperimentPlanEntry`, `generate_experiment_plan`, `load_experiment_plan` | statische 100-Punkte-LHS-Datei erzeugen/validieren |
| `src/experiments/experiment_runner.py` | `ExperimentRunner.run` | ausgewählten Bereich eines Plans seriell ausführen |
| `src/results/csv_cycle_recorder.py` | `CsvCycleRecorder.record` | Ergebniszeilen anhängen und auf Datenträger synchronisieren |
| `src/optimizer/config.py` | `OptimizerConfig`, `load_optimizer_config` | JSON-Schema, Grenzen und Pfade validieren |
| `src/optimizer/warm_start.py` | `WarmStartGenerator`, `propose_next` | LHS-, Random- oder Sobol-Warmstart erzeugen |
| `src/optimizer/strategies.py` | Strategieklassen und `build_strategy` | adaptive oder batchweise Folgevorschläge |
| `src/optimizer/experiment_store.py` | `ExperimentStore`, `RunRecord`, `ExperimentState` | transaktionale Laufpersistenz und Resume-Regeln |
| `src/optimizer/framework_runner.py` | `FrameworkRunner`, `SyntheticSurfaceExecutor` | Simulation und gemeinsame Optimierersteuerung |
| `src/optimizer/hardware_executor.py` | `OrchestratorRunExecutor` | Optimierer-Vorschlag in einen Orchestratorlauf übersetzen |
| `src/optimizer/hardware_cli.py` | CLI-Steuerung und Sicherheitsgates | Preflight, Bestätigung, Retry und manuelle Freigabe |

## Zentrale Datenmodelle

### Einzelzyklus

`CycleRequest` verbindet eine `cycle_id`, den Modus, STL-, Profil- und G-Code-Pfade sowie ein `PrintParameters`-Objekt. `CycleResult` enthält Status, letzte Stufe, Zeitpunkte, Pfade, Druckerzustände, Bildpfad, `Ra_um`, `Rz_um` und gegebenenfalls eine Fehlermeldung. Der statische Recorder flacht dieses Objekt in eine CSV-Zeile ab.

Die Cycle-ID wird als UUID erzeugt. Der Kamera-Endpunkt akzeptiert deren hexadezimale Darstellung ohne Bindestriche (`uuid.hex`, 32 Kleinbuchstaben/Ziffern).

### Optimiererzustand

`ExperimentState` hält Gesamtzahl, Zahl abgeschlossener Läufe, aktuelle Run-Nummer und Pauseninformationen. Der Status jedes einzelnen geplanten, laufenden oder abgeschlossenen Satzes steht im jeweiligen `RunRecord`; dieser enthält außerdem Parameter, Strategie, Optimiereriteration, Attempt-Zähler und Ergebnis. Der Store schreibt getrennte JSON-Dateien und baut daraus `results.csv` neu auf.

```mermaid
stateDiagram-v2
    [*] --> proposed: Vorschlag persistent
    proposed --> running: Hardwarestart
    running --> completed: gültige Messung
    running --> retryable_failed: vergleichbarer Fehler
    running --> terminal_failed: unsicherer Fehler
    retryable_failed --> proposed: gleicher Satz, Retry
    retryable_failed --> completed: Penalty oder Ignore
    terminal_failed --> proposed: manuell freigegeben
    completed --> [*]
```

`running` ist ein persistenter Status, für den die aktuelle CLI nach einem Prozessabbruch keinen expliziten Wiederherstellungsbefehl anbietet. Dies ist kein erlaubter manueller JSON-Edit, sondern ein offener Implementierungspunkt.

## Modulabhängigkeiten

```mermaid
flowchart TD
    CLI["main / hardware_cli"] --> ORC["PrintOrchestrator"]
    CLI --> OPT["OptimizerConfig + Strategien"]
    OPT --> STORE["ExperimentStore"]
    ORC --> ADAPTER["Slicer, Drucker, Roboter, QS, Kamera"]
    ORC --> REC["CsvCycleRecorder"]
    ADAPTER --> DEV["Externe Prozesse, HTTP und Hardware"]
```

Die Hardwareklassen sind im Orchestrator über kleine Protocol-Schnittstellen entkoppelt. Dadurch ersetzen die Tests Slicer, Drucker, Roboter, QS und Kamera durch Fakes, ohne reale Geräte anzusprechen. Das Optimierer-Framework kapselt die Ausführung zusätzlich über einen Executor: `SyntheticSurfaceExecutor` für Simulation und `OrchestratorRunExecutor` für den realen Orchestrator.

## Zuständigkeit der Persistenz

Es existieren zwei bewusst getrennte Speicherwege:

- `CsvCycleRecorder`: append-only CSV für `main --mode full|robot-qs|experiment`; kennt keine Optimiereriteration oder Attempt-Nummer.
- `ExperimentStore`: JSON-Zustand plus atomar neu erzeugte CSV für den Optimierer; kennt Retry, Penalty, Ignore und Strategie-Checkpoint.

Eine statische Ergebnis-CSV kann deshalb nicht direkt als Optimiererzustand fortgesetzt werden. `paths.history_csvs` wird zwar vom Konfigurationsschema akzeptiert, die aktuellen Runner lehnen eine nicht leere Historienliste aber ausdrücklich ab.

## Architekturrelevante Altdateien

Die Dateien `docs/OPTIMIZER_FRAMEWORK_STEP_*.md`, `docs/END_TO_END_SINGLE_CYCLE.md`, `docs/robot_positions.md`, `src/docs/ROBOT_POSITIONS.md` und `src/robot/generate_position_docs.py` dokumentieren Zwischenstände. Insbesondere Fehler-Retries und Robotersequenzen stimmen dort teilweise nicht mehr mit `src/orchestrator.py` beziehungsweise `src/robot/robot_service.py` überein. Für Änderungen gilt der aktuelle Code als Quelle.

Weiter: [03 – Installation](03_installation.md)

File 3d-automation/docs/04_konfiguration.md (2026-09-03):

# 04 – Konfiguration

## Grundprinzip und Prioritäten

Es gibt keine globale Kaskade „CLI vor JSON vor Env“. Die Quellen sind komponentenspezifisch:

1. `main.py`: Dateipfade und sechs Einzelzyklusparameter kommen aus CLI-Argumenten. Nicht angegebene Parameter werden aus dem per CLI gewählten Basisprofil gelesen.
2. Hardwareadressen und Zeitwerte des Orchestrators kommen ausschließlich aus Umgebungsvariablen oder den in `main.py` codierten Defaults.
3. Das Optimierer-Framework liest Experiment, Grenzen, Strategie und Pfade ausschließlich aus einer JSON-Datei. Hardwarezugang und Orchestrator-Timeouts bleiben Env-Werte.
4. Die Hardware-CLI setzt während der Objekterzeugung gegebenenfalls den Kamera-Downloadpfad auf das Laufverzeichnis.

Relative Optimiererpfade werden relativ zum Verzeichnis der JSON-Datei aufgelöst. Relative Kamera-Ausgabepfade der Pi-API hängen dagegen vom Arbeitsverzeichnis des Uvicorn-Prozesses ab.

## Umgebungsvariablen auf dem Hauptrechner

Quelle: `src/main.py:build_orchestrator`.

| Name | Bedeutung | Typ | Einheit | Standard | Bereich/Format | Pflicht | Quelle | Beispiel |
| --- | --- | --- | --- | --- | --- | --- | --- | --- |
| `PRINTER_IP` | PrusaLink-Host | Text | – | `10.8.170.57` | Host/IP ohne Schema und Port | optional | `main.py:build_orchestrator` | `10.8.170.57` |
| `PRUSALINK_API_KEY` | PrusaLink-Zugang | geheimer Text | – | keiner | nicht leer | **ja** | `main.py:required_environment` | `REPLACE_WITH_NEW_API_KEY` |
| `ROBOT_IP` | Niryo-Adresse | Text | – | `10.8.170.41` | Host/IP | optional | `main.py:build_orchestrator` | `10.8.170.41` |
| `QS_BASE_URL` | QS-API | URL-Text | – | keiner | nicht leer, mit Schema/Port | **ja** | `main.py:required_environment` | `http://192.0.2.10:8000` |
| `CAMERA_BASE_URL` | separate Kamera-API | URL-Text | – | `QS_BASE_URL` | mit Schema/Port | optional | `main.py:build_orchestrator` | `http://192.0.2.10:8000` |
| `PRUSASLICER_PATH` | ausführbarer Slicer | Pfadtext | – | `~/apps/prusaslicer/PrusaSlicer-2.9.1-x86_64.AppImage` | vorhandene, ausführbare Datei | optional | `main.py:build_orchestrator` | `/opt/PrusaSlicer.AppImage` |
| `REMOTE_GCODE_PATH` | USB-Ziel im Drucker | Pfadtext | – | `FOLDER/demo.gcode` | relativer sicherer Pfad | optional | `main.py:build_orchestrator` | `FOLDER/demo.gcode` |
| `CAMERA_DOWNLOAD_DIR` | lokale JPEG-Kopien | Pfadtext | – | Projekt-`data/camera_images` | beschreibbares Verzeichnis | optional | `main.py:build_orchestrator` | `data/camera_images` |
| `PRINT_POLL_SECONDS` | Druckstatusintervall | float | s | `15` | >= 0 | optional | `main.py`, `PrintOrchestrator.__init__` | `15` |
| `PRINT_START_TIMEOUT_SECONDS` | Frist bis aktiv | float | s | `180` | > 0 | optional | `main.py`, `PrintOrchestrator.__init__` | `180` |
| `PRINT_TIMEOUT_SECONDS` | gesamte Überwachungsfrist | float | s | `28800` | > 0 | optional | `main.py`, `PrintOrchestrator.__init__` | `28800` |
| `MAX_STATUS_ERRORS` | aufeinanderfolgende Statusfehler | int | Anzahl | `5` | > 0 | optional | `main.py`, `PrintOrchestrator.__init__` | `5` |
| `PART_COOLING_SECONDS` | Wartezeit vor Robotik | float | s | `60` | >= 0 | optional | `main.py`, `PrintOrchestrator.__init__` | `60` |

Sichere Muster stehen in `config/end_to_end.env.example` für den Hauptrechner und `config/qs_station.env.example` für den Raspberry Pi. Sie enthalten nur Platzhalter beziehungsweise dokumentierte Defaults.

### Feste, derzeit nicht extern konfigurierbare Zeitwerte

| Komponente | Wert | Quelle |
| --- | --- | --- |
| PrusaLink normaler Request | 10 s | `PrusaLinkService.__init__` |
| PrusaLink Upload | 300 s Read-Timeout | `PrusaLinkService.__init__` |
| PrusaLink Verbindungswait | 20 Versuche, 10 s Abstand | `PrusaLinkService.wait_until_connected` |
| PrusaSlicer | 600 s | `SlicerService.__init__` |
| QS-Client Health / Messung | 5 s / 90 s | `QualityStationClient.__init__` |
| Kamera-Client Health / Capture / Download | 5 s / 30 s / 30 s | `CameraClient.__init__` |
| Orchestrator QS-Health-Wait | 300 s, 10 s Abstand | `PrintOrchestrator._wait_for_quality_station_health` |

Diese Werte können nur durch Konstruktorübergabe oder Codeänderung angepasst werden; `main.build_orchestrator()` bietet dafür keine Env-Variablen.

## Umgebungsvariablen auf dem Raspberry Pi

Quelle: `src/qs/api.py`.

| Name | Bedeutung | Typ | Einheit | Standard | Bereich/Format | Pflicht | Quelle | Beispiel |
| --- | --- | --- | --- | --- | --- | --- | --- | --- |
| `CAMERA_DEVICE_PATH` | V4L2-Kamera | Pfadtext | – | `/dev/video0` | existierendes Gerät | optional | `qs/api.py:_camera_device_path` | `/dev/video0` |
| `CAMERA_OUTPUT_DIR` | JPEG-Speicher auf Pi | Pfadtext | – | `data/camera_images` | beschreibbar; relativ zum Server-Arbeitsverzeichnis | optional | `qs/api.py:_camera_output_directory` | `/srv/qs/images` |
| `CAMERA_WIDTH` | Aufnahmebreite | int | Pixel | `1920` | Code prüft nicht; muss Kamera/ffmpeg unterstützen | optional | `qs/api.py:_camera_width` | `1920` |
| `CAMERA_HEIGHT` | Aufnahmehöhe | int | Pixel | `1080` | Code prüft nicht; muss Kamera/ffmpeg unterstützen | optional | `qs/api.py:_camera_height` | `1080` |
| `CAMERA_PIXEL_FORMAT` | Eingabeformat | Text | – | `mjpeg` | Code prüft nicht; V4L2-/ffmpeg-Format | optional | `qs/api.py:_camera_pixel_format` | `mjpeg` |

Serieller Gerätepfad und Baudrate sind in `src/qs/api.py:create_measurement` fest auf `/dev/ttyUSB0` und `38400` gesetzt und derzeit nicht über Env konfigurierbar.

## CLI von `main`

Quelle: `src/main.py:parse_arguments`. Pfade sind relativ zum aktuellen Arbeitsverzeichnis interpretierbar; die Defaults sind absolute Pfade unter `3d-automation/`.

| Argument | Typ / Default | Wirkung |
| --- | --- | --- |
| `--mode` | Enum; `preflight` | `preflight`, `robot-qs`, `full` oder `experiment` |
| `--stl` | Pfad; `data/models/15x15_V2_rounded.stl` | Eingabemodell |
| `--profile` | Pfad; `config/slicer_profile.ini` | vollständiges Basisprofil |
| `--generated-profiles-dir` | Pfad; `data/generated_profiles` | erzeugte INI-Dateien |
| `--gcode` | Pfad; `data/gcode/output.gcode` | Einzeldatei; im Experiment bestimmt nur das Elternverzeichnis |
| `--results-csv` | Pfad; `data/results/parameter_optimization_cycles.csv` | append-only Zyklusergebnisse |
| `--experiment-plan` | Pfad; `config/experiment_plans/experiment_plan_100.csv` | exakt 100 Planzeilen |
| `--experiment-cycles` | int 1…100; `2` | **letzte** auszuführende Plannummer, nicht Anzahl |
| `--experiment-start-cycle` | int 1…100; `1` | erste auszuführende Plannummer |
| `--reuse-experiment-plan` | Flag; aus | bestehenden Plan zwingend unverändert wiederverwenden |
| `--experiment-plan-seed` | int; keiner | Reproduzierbarkeit bei Neugenerierung; unvereinbar mit Reuse |
| `--top-solid-layers` | int; Profilwert | obere Vollschichten |
| `--print-speed` | float, mm/s; Profilwert | Geschwindigkeit oberer Vollfüllung |
| `--extrusion-width` | float, mm; Profilwert | Extrusionsbreite der oberen Füllung |
| `--extrusion-multiplier` | float; Profilwert | globaler Extrusionsfaktor |
| `--temperature` | int, °C; Profilwert | Düsentemperatur nach erster Schicht |
| `--fan-speed` | int, %; `max_fan_speed` aus Profil | min./max./Brückenlüfter im erzeugten Profil |

Die Hilfe nennt historische Experimentgrenzen und bezeichnet `top_solid_layers` als fest. Die eigentliche Klasse `PrintParameters` erlaubt jedoch: `top_solid_layers >= 0`, `print_speed > 0`, `extrusion_width > 0`, `extrusion_multiplier > 0`, `temperature >= 0`, `fan_speed` von 0 bis 100. Diese intrinsischen Prüfungen sind keine Aussage über sichere Material- oder Maschinengrenzen. Für reale Versuche müssen enger validierte Grenzen verwendet werden.

Im Modus `experiment` sind die sechs Parameterargumente verboten; die Werte kommen vollständig aus der CSV.

## Optimierer-CLI-Argumente

| Einstieg | Argument | Regel / Bedeutung |
| --- | --- | --- |
| alle Optimierer-CLIs | `config` | Pfad zur JSON, positionsabhängig |
| `optimizer.config` | `--check-input-files` | zusätzlich STL, Profil und History-Pfade prüfen |
| `framework_runner` | genau eines `--new`, `--resume` | Store anlegen oder öffnen |
| `framework_runner` | `--simulate` | zwingende Bestätigung, dass der Simulator verwendet wird |
| `framework_runner` | `--from-run N` | erwartete nächste Nummer beim Resume |
| `framework_runner` | `--max-runs N` | maximal in diesem Prozess abgeschlossene Sätze; ohne Angabe bis Ende/Stopp |
| `framework_runner` | `--retry-failed` | gespeicherten retry-fähigen Satz identisch vorbereiten |
| `hardware_cli` | genau eines `--new`, `--resume` | Anlegen oder Öffnen des Stores |
| `hardware_cli` | `--from-run N` | Resume-Konsistenz; bei manueller Freigabe Pflicht |
| `hardware_cli` | `--max-runs N` | Default 1 abgeschlossener Satz; automatischer Retry kann Extra-Zyklus erzeugen |
| `hardware_cli` | `--retry-failed` | einen gespeicherten retry-fähigen Run vorbereiten |
| `hardware_cli` | `--automatic-retry` | ersten vergleichbaren Fehlschlag einmal automatisch wiederholen; nur Resume |
| `hardware_cli` | `--failure-result penalty\|ignore` | experimentweite, danach unveränderliche Fehlerbeobachtung |
| `hardware_cli` | `--resume-after-manual-intervention` | terminalen Run nach Anlagenprüfung freigeben; nur mit Resume, `--from-run`, Preflight |
| `hardware_cli` | `--acknowledge-failure-streak` | Pause nach drei Fehlsätzen quittieren; Alias `--acknowledge-penalty-streak` |
| `hardware_cli` | `--preflight-only` | Vorschlag speichern/Dienste prüfen, keine physische Ausführung |
| `hardware_cli` | `--confirm-hardware` | Pflicht für physischen Lauf; bei Preflight verboten |

`optimizer.warm_start` besitzt außer dem Config-Pfad keine Option. Ein neuer Hardwarestore darf nur mit `--new --preflight-only` angelegt werden.

## Optimierer-JSON

Quelle: `src/optimizer/config.py`, Schema `1`. Unbekannte Felder werden abgelehnt.

| Feld | Bedeutung | Typ / Einheit | Default | Bereich/Format | Pflicht | Beispiel |
| --- | --- | --- | --- | --- | --- | --- |
| `schema_version` | Konfigurationsschema | int / – | keiner | genau `1` | ja | `1` |
| `experiment_name` | Bezeichner im Snapshot | Text / – | keiner | nicht leer | ja | `surface_roughness_bo_example` |
| `total_runs` | endgültige Parametersätze | int / Anzahl | keiner | >= 1 und Batchregeln | ja | `100` |
| `seed` | deterministische Zufallsquelle | int / – | keiner | >= 0 | ja | `42` |
| `objective` | zu minimierende Größe | Text / µm | keiner | genau `Ra_um` | ja | `Ra_um` |
| `warm_start.method` | Initialdesign | Enum / – | keiner | `lhs`, `random`, `sobol` | ja | `lhs` |
| `warm_start.sample_count` | Initialpunkte/Batchgröße | int / Anzahl | keiner | >= 1; BO/PSO >= 2, DE >= 4 | ja | `10` |
| `strategy.name` | Hauptstrategie | Enum / – | keiner | dokumentierte Namen/Aliase | ja | `bayesian` |
| `strategy.options` | Strategieparameter | Objekt / – | `{}` | nur erlaubte Schlüssel | nein | `{"acquisition":"ei"}` |
| `parameters` | variable Parameter | Liste / je Parameter | keiner | nicht leer; je `name`, `lower`, `upper` | ja | `[ {"name":"print_speed",...} ]` |
| `fixed_parameters` | feste Parameter | Objekt / je Parameter | keiner | zusammen mit `parameters` genau alle sechs | ja | `{"top_solid_layers":5}` |
| `paths.stl` | STL-Eingabe | Pfadtext / – | keiner | relativ zur JSON oder absolut | ja | `../data/models/15x15_V2_rounded.stl` |
| `paths.base_profile` | Slicer-Basisprofil | Pfadtext / – | keiner | relativ zur JSON oder absolut | ja | `slicer_profile.ini` |
| `paths.output_directory` | Laufverzeichnis | Pfadtext / – | keiner | bei `--new` noch nicht vorhanden | ja | `../data/optimization_runs/run_001` |
| `paths.history_csvs` | Altbeobachtungen | Liste / – | `[]` | eindeutige Pfade; aktuelle Runner verlangen leer | nein | `[]` |

Quelle für alle JSON-Felder ist `src/optimizer/config.py`; die Beispielwerte stammen aus `config/optimizer_config.example.json`.

Jeder der sechs unterstützten Parameter muss **genau einmal** entweder variabel oder fest vorkommen. Variable Untergrenze muss kleiner als Obergrenze sein. Für batchbasierte Strategien muss `total_runs - sample_count` durch `sample_count` teilbar sein; Bayesian Optimization erzeugt dagegen Einzelvorschläge.

### Parameterdomänen und Rundung

| Parameter | Einheit | Typ/Rundung | intrinsische Code-Domäne | Beispielgrenze |
| --- | --- | --- | --- | --- |
| `top_solid_layers` | Schichten | int | >= 0 | im Beispiel fest `5` |
| `print_speed` | mm/s | 1 Dezimalstelle | > 0 | 50…90 |
| `extrusion_width` | mm | 3 Dezimalstellen | > 0 | 0,38…0,50 |
| `extrusion_multiplier` | Faktor | 3 Dezimalstellen | > 0 | 1,05…1,20 |
| `temperature` | °C | int | >= 0 | 215…235 |
| `fan_speed` | % | int | 0…100 | 30…80 |

Die Beispielgrenzen stammen aus `config/optimizer_config.example.json`, nicht aus einer allgemeinen Maschinensicherheitsfreigabe. Die JSON darf andere Werte innerhalb der breiten intrinsischen Domäne angeben. Der Betreiber trägt die Verantwortung für material- und hardwaregerechte Grenzen.

### Strategieoptionen

| Strategie | Option | Default | gültig |
| --- | --- | --- | --- |
| Bayesian | `acquisition` | `ei` | `ei` oder `thompson` |
| Bayesian | `candidate_count` | `4096` | int >= 64 |
| Bayesian | `n_restarts_optimizer` | `5` | int >= 0 |
| PSO | `inertia` | `0.7` | 0…1 |
| PSO | `cognitive_weight` | `1.5` | >= 0 |
| PSO | `social_weight` | `1.5` | >= 0 |
| PSO | `max_velocity` | `0.2` | > 0 und <= 1 |
| Differential Evolution | `differential_weight` | `0.8` | > 0 und <= 2 |
| Differential Evolution | `crossover_probability` | `0.9` | 0…1 |
| Random/Sobol | keine | – | unbekannte Optionen werden abgelehnt |

Penalty ist kein JSON-Feld: `--failure-result penalty` oder `ignore` speichert die Experimententscheidung; vor `--automatic-retry` ist eine solche persistierte Wahl Pflicht. Ohne gespeicherte Wahl verwendet ein nicht automatischer Hardwareaufruf intern Penalty als Default. Der numerische Wert ist im aktuellen `FailurePolicy` fest `100.0`. Logging hat ebenfalls kein Konfigurationsfeld: alle CLIs nutzen `INFO`, die Hardware-CLI schreibt zusätzlich `optimizer_hardware.log`.

| Feste Fehleroption | Wert | Konfigurierbar? | Quelle |
| --- | --- | --- | --- |
| vergleichbare Attempts pro Optimierer-Run | 2 | nicht per CLI/JSON | `FailurePolicy.maximum_attempts_per_run` |
| Penalty-Zielfunktionswert | 100,0 | nicht per CLI/JSON | `FailurePolicy.penalty_value` |
| Sicherheitsstopp nach Fehlsätzen | 3 nacheinander | nicht per CLI/JSON | `FailurePolicy.maximum_consecutive_failed_parameter_sets` |
| zusätzlicher QS-Aufruf im Orchestrator | 1 nach erstem Fehler | nein | `PrintOrchestrator._run_cycle` |
| SJ-Leseretrys bei `011`/`033` | insgesamt 5 Versuche | nur Konstruktor | `SJ220Service.__init__` |

## Slicer-Profil und Abbildung

`SlicerProfileGenerator` bewahrt alle nicht betroffenen Zeilen des Basisprofils und ersetzt:

| Logischer Parameter | Slicer-Schlüssel |
| --- | --- |
| `top_solid_layers` | `top_solid_layers` |
| `print_speed` | `top_solid_infill_speed` |
| `extrusion_width` | `top_infill_extrusion_width` |
| `extrusion_multiplier` | `extrusion_multiplier` |
| `temperature` | `temperature` |
| `fan_speed` | `min_fan_speed`, `max_fan_speed`, `bridge_fan_speed` |

Zusätzlich werden konstante Versuchsbedingungen erzwungen: `skirts=0`, `brim_width=0`, `top_solid_min_thickness=0`, `slowdown_below_layer_time=0`, `enable_dynamic_fan_speeds=0`. Fehlt ein benötigter Schlüssel im Basisprofil, bricht die Generierung ab.

Das aktuelle `config/slicer_profile.ini` enthält unter anderem Schichthöhe `0.2`, Fülldichte `0%`, Bett `60 °C`, erste Schicht `230 °C` bei Geschwindigkeit `15`, danach `220 °C`, fünf obere Vollschichten, Geschwindigkeit `80 mm/s`, Breite `0.42 mm`, Extrusionsfaktor `1.05` und Lüfter `80 %`. `slicer_profile_flat.ini` ist leer und nicht verwendbar; `slicer_profile_meins.ini` ist ein abweichender Altstand.

## Sichere Konfigurationsverwaltung

- Keine API-Schlüssel, Passwörter oder Tokens in Markdown, JSON, Git oder Screenshots aufnehmen.
- Vor `--new` einen neuen `paths.output_directory` wählen; ein bestehendes Verzeichnis wird absichtlich nicht überschrieben.
- Für `--resume` dieselbe JSON am selben Ort und dasselbe Zielverzeichnis verwenden. Der gespeicherte Hash enthält aufgelöste absolute Pfade; selbst ein Verschieben kann daher als Konfigurationsänderung gelten.
- Nach Start eines Optimierungslaufs Grenzen und Strategie nicht nachträglich ändern. Der Konfigurationssnapshot ist Teil der Reproduzierbarkeit.

Weiter: [05 – Hardware-Setup](05_hardware_setup.md)

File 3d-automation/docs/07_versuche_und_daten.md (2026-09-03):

# 07 – Versuche und Daten

## Zwei Datenmodelle

Das Projekt besitzt zwei Ausführungs- und Speicherwege:

| Weg | Start | Primärer Zustand | Wiederaufnahme |
| --- | --- | --- | --- |
| statischer Plan / Einzelzyklus | `python -m main` | append-only `parameter_optimization_cycles.csv` | manuell über Planbereich |
| Optimierer | `optimizer.framework_runner` oder `optimizer.hardware_cli` | `ExperimentStore` mit JSON, Checkpoints und neu gebauter `results.csv` | zustandsbasiert über `--resume` |

Diese Formate sind nicht austauschbar. Besonders enthält die statische CSV weder Optimiereriteration noch Attempt-Nummer.

## Statischer Versuchsplan

Die CSV-Kopfzeile muss exakt lauten:

```csv
cycle_number,top_solid_layers,print_speed,extrusion_width,extrusion_multiplier,temperature,fan_speed
```

Beispiel einer syntaktisch gültigen Zeile:

```csv
1,5,80,0.42,1.05,220,80
```

| Spalte | Einheit | Bedeutung |
| --- | --- | --- |
| `cycle_number` | – | fortlaufend ab 1, lückenlos |
| `top_solid_layers` | Schichten | Zahl oberer Vollschichten |
| `print_speed` | mm/s | Geschwindigkeit oberer Vollfüllung |
| `extrusion_width` | mm | Breite der oberen Füllung |
| `extrusion_multiplier` | Faktor | Extrusionsmengenfaktor |
| `temperature` | °C | Düsentemperatur nach der ersten Schicht |
| `fan_speed` | % | fester Lüfterwert im erzeugten Profil |

`load_experiment_plan()` prüft Header, Zahlen, fortlaufende Cycle-Nummern, erwartete Zeilenzahl und eindeutige Parametersätze. `main --mode experiment` setzt die erwartete Zahl fest auf 100.

### Automatische Plangenerierung

`generate_experiment_plan()` verwendet einen Latin Hypercube aus der Python-Standardbibliothek `random`. Jede Dimension erhält einen zufälligen Punkt je gleich großem Intervall und wird unabhängig gemischt. Die festen Grenzen sind:

| Parameter | Bereich |
| --- | --- |
| `top_solid_layers` | fest 5 |
| `print_speed` | 50…90 mm/s |
| `extrusion_width` | 0,38…0,50 mm |
| `extrusion_multiplier` | 1,05…1,20 |
| `temperature` | 215…235 °C |
| `fan_speed` | 30…80 % |

Ohne Seed wird ein zufälliger 63-Bit-Seed erzeugt und im Log genannt. Der Plan wird zunächst in `config/experiment_plans/archive/` geschrieben und dann atomar aktiviert. Eine vorhandene aktive CSV wird zusätzlich als `..._replaced_...csv` archiviert.

## Profil- und G-Code-Erzeugung

Für jeden Zyklus erzeugt `SlicerProfileGenerator` ein vollständiges, vom Basisprofil abgeleitetes INI. Einzelzyklen landen standardmäßig in `data/generated_profiles/`; statische Planläufe verwenden zyklusbezogene Dateinamen. Im Optimierer heißen sie beispielsweise:

```text
generated_profiles/run_0007_attempt_02_profile.ini
gcode/run_0007_attempt_02.gcode
```

Der Generator ersetzt die sechs Parameter sowie fünf feste Versuchsbedingungen. Das erzeugte Profil wird über SHA-256 im statischen Ergebnis erfasst. `SlicerService` löscht eine schon vorhandene G-Code-Zieldatei vor dem Aufruf und wartet höchstens 600 Sekunden. Dadurch ist die Zieldatei kein Archiv: Eindeutige Run-/Attempt-Namen sind wichtig.

## Ergebnis eines Einzel- oder Planzyklus

Standardpfad: `data/results/parameter_optimization_cycles.csv`. Das Schema ist stabil und wird vor jedem Append mit der vorhandenen Kopfzeile verglichen.

| Feld | Inhalt |
| --- | --- |
| `cycle_id` | UUID-Text des physischen Zyklus |
| `mode` | `full` oder `robot-qs` |
| `status` | `completed` oder Fehlerstatus des `CycleResult` |
| `failed_stage` | bei Erfolg leer, sonst letzte Stufe |
| `error` | Fehlermeldung oder leer |
| `started_at`, `finished_at` | ISO-8601-Zeitpunkte |
| `duration_seconds` | Laufzeit, auf 3 Stellen gerundet |
| `stl_path`, `profile_path`, `gcode_path` | verwendete lokale Pfade |
| `profile_sha256` | Hash des erzeugten Profils |
| `camera_image_path` | lokale JPEG-Kopie oder leer |
| `Ra_um`, `Rz_um` | Rauheitswerte in µm |
| `printer_states` | beobachtete Zustände, mit ` -> ` verbunden |
| `parameter_*` | sechs tatsächlich verwendete Parameter |

Die Datei wird nach jeder Zeile geflusht und per `fsync` synchronisiert. Sie enthält aber keine globale Transaktion zusammen mit G-Code oder Bild. Ein harter Abbruch zwischen Teilschritten kann deshalb unvollständige Artefakte hinterlassen.

## Optimierer-Laufverzeichnis

Ein neu angelegter `ExperimentStore` erzeugt:

```text
<output_directory>/
├── config_snapshot.json
├── run_state.json
├── results.csv                    # nach Ergebnissen erzeugt
├── runs/run_0001.json
├── attempt_history/
├── optimizer_state/
├── generated_profiles/
├── gcode/
├── logs/
├── hardware_cycles.csv            # nur Hardware-CLI
└── images/                         # nur Hardware-CLI
```

### `config_snapshot.json`

Enthält die normalisierte Konfiguration mit absoluten Pfaden. `source_path` wird gespeichert; der Konfigurationshash wird allerdings ohne `source_path`, aber mit den übrigen aufgelösten Pfaden berechnet. Deshalb kann ein Umzug von Daten, Profil oder Zielverzeichnis einen Resume verhindern.

### `run_state.json`

| Feldgruppe | Beispiele / Bedeutung |
| --- | --- |
| Identität | `experiment_id`, `experiment_name`, `config_sha256` |
| Fortschritt | `status`, `total_runs`, `completed_runs`, `current_run_number` |
| Fehlerserie | `consecutive_penalty_runs`, `consecutive_ignored_runs`, `consecutive_failed_parameter_sets` |
| Policy | `failure_observation_mode` = `penalty`, `ignore` oder `null` |
| Pause | `last_error`, `pause_reason`, `resume_run_number` |
| Audit | `created_at`, `updated_at` |

Der Store gleicht beim Öffnen den zusammengefassten Zustand mit den einzelnen Run-Dateien ab. Hash-, Schema- oder Sequenzwidersprüche führen zum Abbruch statt zu stiller Korrektur.

### `runs/run_NNNN.json`

Jeder Run enthält:

- `run_number`, `attempt_number`, `status`;
- Strategie und `optimizer_iteration` (`null` im Warmstart);
- alle sechs Parameter;
- `cycle_id`, `objective_value`, `Ra_um`, `Rz_um`;
- `is_penalty`, `is_ignored`, `soft_failure_count`;
- `failed_stage`, `error` und Zeitpunkte.

Der aktuelle Datensatz ist die autoritative Sicht auf einen Parametersatz. Frühere Zustände werden vor relevanten Übergängen in `attempt_history/run_NNNN_attempt_NN*.json` archiviert.

### `optimizer_state/`

Dateien wie `bayesian_iteration_0000.json` enthalten einen Checkpoint samt bereits festgelegtem Vorschlagsbatch. Der Checkpoint wird vor dem ersten physischen Lauf des Batches gespeichert. Nach Resume wird deshalb derselbe Vorschlag verwendet und kein neuer Zufallspunkt erzeugt.

## `results.csv` des Optimierers

Die Datei wird atomar aus allen abgeschlossenen Run-JSONs neu aufgebaut.

| Feld | Bedeutung |
| --- | --- |
| `run_number`, `attempt_number` | Parametersatz und letzter physischer/manueller Versuch |
| `strategy`, `optimizer_iteration` | Erzeuger und Iteration; Warmstartiteration leer |
| sechs Parameterfelder | tatsächlich vorgeschlagener, quantisierter Satz |
| `objective_value` | für Optimierung verwendeter Wert; `Ra_um` oder Penalty 100 |
| `Ra_um`, `Rz_um` | echte Messung; bei Penalty/Ignore leer |
| `observation_kind` | `measured`, `penalty` oder `ignored_failure` |
| `is_penalty`, `is_ignored` | boolesche Kennzeichen |
| `soft_failure_count` | Zahl vergleichbarer Fehlschläge |
| `failed_stage`, `error`, `cycle_id` | Diagnose und physische Zuordnung |

Beispielschema, Werte nur illustrativ:

```csv
run_number,attempt_number,strategy,optimizer_iteration,top_solid_layers,print_speed,extrusion_width,extrusion_multiplier,temperature,fan_speed,objective_value,Ra_um,Rz_um,observation_kind,is_penalty,is_ignored,soft_failure_count,failed_stage,error,cycle_id
1,1,bayesian,,5,72.0,0.421,1.08,222,55,4.2,4.2,24.8,measured,False,False,0,,,0123456789abcdef0123456789abcdef
```

## Bilder und Logs

Die Pi-API speichert `<cycle_id>.jpg` in `CAMERA_OUTPUT_DIR`. Der Hauptrechner lädt dasselbe Bild nach `CAMERA_DOWNLOAD_DIR`; die Hardware-CLI setzt dieses Verzeichnis auf `<output_directory>/images`. `hardware_cycles.csv` referenziert die lokale Datei.

`optimizer_hardware.log` enthält INFO-Logs der Hardware-CLI und der aufgerufenen Module. Einzel-/Planläufe loggen standardmäßig nur auf die Konsole. Die Logkonfiguration ist aktuell nicht über Datei oder CLI einstellbar.

## Retry, Penalty und Ignore in den Daten

- Ein Fehler vor physischem Verbrauch (`preflight`, `slicing`) behält den Attempt für eine Korrektur frei.
- Ein vergleichbarer Fehler verbraucht einen Attempt. `prepare_retry()` behält dieselben Parameter und erhöht `attempt_number`.
- Nach zwei vergleichbaren Fehlschlägen wird der Run abgeschlossen: bei `penalty` mit `objective_value=100`, bei `ignore` ohne Zielfunktionswert.
- Ein terminaler Fehler bleibt `terminal_failed`, bis der Operator ihn nach Anlagenprüfung freigibt; manuelle Freigaben können Attempt-Nummern über 2 erzeugen.
- Drei aufeinanderfolgende endgültig fehlgeschlagene Parametersätze setzen `pause_reason` und `resume_run_number`.

## Überschreiben und doppelte Ergebnisse vermeiden

1. Für jeden neuen Optimiererlauf ein noch nicht vorhandenes Zielverzeichnis wählen; `ExperimentStore.create()` verweigert Überschreiben.
2. Nie Run-JSON, Checkpoint oder `run_state.json` von Hand ändern.
3. Für Resume unveränderte Konfiguration und Pfade verwenden.
4. Statische Pläne nur mit `--reuse-experiment-plan` fortsetzen und Startnummer gegen CSV und physische Teile prüfen.
5. Vor Backup den Prozess sauber beenden; immer das komplette Laufverzeichnis gemeinsam kopieren.
6. `results.csv` als Lesesicht behandeln, Run-JSONs als Quelle des Optimiererzustands.

Weiter: [08 – Optimierer](08_optimierer.md)

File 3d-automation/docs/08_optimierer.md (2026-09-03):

# 08 – Optimierer

## Ziel und Umfang

Der Optimierer minimiert ausschließlich `Ra_um`, die arithmetische Mittenrauheit in Mikrometern. `Rz_um` wird gespeichert, aber nicht zur Auswahl des nächsten Punkts verwendet. Der Optimierer steuert sechs logische Druckparameter; jeder davon ist in der JSON entweder variabel oder fest.

Der aktuelle Stand enthält ein integriertes, persistentes Vorschlags- und Hardwareframework. Nicht implementiert sind Import historischer CSV-Daten, QBC (Query by Committee), Mehrzieloptimierung, automatische Bildauswertung und der im frühen Projektpitch skizzierte Vergleich von kNN, SVR, LightGBM, CatBoost oder MLP.

## Prozess

```mermaid
flowchart TD
    C["OptimizerConfig laden"] --> S["ExperimentStore öffnen/erzeugen"]
    S --> W{"Warmstart vollständig?"}
    W -- Nein --> P["Warmstartpunkt vorschlagen"]
    W -- Ja --> O["Strategie-Checkpoint und Vorschlag"]
    P --> E["Simulator oder OrchestratorRunExecutor"]
    O --> E
    E --> R["Messung, Penalty oder Ignore speichern"]
    R --> T{"total_runs erreicht?"}
    T -- Nein --> W
    T -- Ja --> F["Experiment completed"]
```

Wesentlich für Crash-Sicherheit: Ein Vorschlag wird vor seiner Ausführung in `runs/` gespeichert. Ein Strategiebatch wird ebenfalls vor Hardwarekontakt im `optimizer_state/` festgeschrieben.

## Parameterraum

`ParameterSpace` transformiert jede variable Dimension linear auf `[0,1]`. Strategien rechnen nur in diesem normierten Raum. Danach wird auf die reale Grenze zurückskaliert und gemäß Parametertyp quantisiert:

| Parameter | Quantisierung | intrinsische Domäne |
| --- | --- | --- |
| `top_solid_layers` | ganze Zahl | >= 0 |
| `print_speed` | 0,1 mm/s | > 0 |
| `extrusion_width` | 0,001 mm | > 0 |
| `extrusion_multiplier` | 0,001 | > 0 |
| `temperature` | ganze °C | >= 0 |
| `fan_speed` | ganzes Prozent | 0…100 |

Die tatsächlichen Experimentgrenzen kommen vollständig aus JSON. Diese weiten Code-Domänen ersetzen keine sichere Druckparameterfreigabe.

## Warmstart

Ein Warmstart ist ein vorab erzeugtes Initialdesign. Erst nach dessen vollständiger Messung startet die Hauptstrategie. `WarmStartGenerator` verwendet NumPy und `scipy.stats.qmc`.

| Methode | Implementierung | Eigenschaft |
| --- | --- | --- |
| `lhs` | `qmc.LatinHypercube` | stratifiziert jede Dimension |
| `random` | `numpy.random.default_rng` | unabhängige Pseudozufallswerte |
| `sobol` | gescrambelte `qmc.Sobol`-Sequenz | niedrig-diskrepante Punktverteilung; intern auf Zweierpotenz erzeugt und gekürzt |

Alle Methoden sind mit `seed` deterministisch. Nach Skalierung und Rundung werden Duplikate entfernt. Reicht der quantisierte Raum nicht aus, bricht die Generierung ab. Maximal 100 Generierungsbatches werden versucht.

Mit `config/optimizer_config.example.json` ergab die verifizierte Vorschau unter anderem als ersten Punkt `top_solid_layers=5`, `print_speed=50.9`, `extrusion_width=0.459`, `extrusion_multiplier=1.052`, `temperature=226`, `fan_speed=45`; derselbe Seed erzeugt dieselbe Folge.

### `WarmStartGenerator.propose_next(store)`

**Eingabe:** ein validierter `ExperimentStore`, dessen Konfiguration zur Generatorinstanz gehört.

**Ausgabe:** ein persistierter `RunRecord`.

Interner Ablauf:

1. Den gesamten deterministischen Warmstart aus Konfiguration und Seed erneut erzeugen.
2. `store.next_run_number()` bestimmen.
3. Abbrechen, wenn das Experiment fertig ist oder die Nummer schon außerhalb der Warmstartphase liegt.
4. Über `load_resume_run()` prüfen, ob dieser Run bereits persistiert ist; dann exakt ihn zurückgeben.
5. Sonst Punkt `run_number - 1` auswählen.
6. Mit `store.propose_run(...)` **vor** der Ausführung speichern; `optimizer_iteration` bleibt `null`.

Die Methode misst nicht, erzeugt keinen G-Code und kontaktiert keine Hardware.

## Verfügbare Hauptstrategien

| Strategie | Batchgröße | Zustand | Voraussetzung |
| --- | --- | --- | --- |
| Bayesian | 1 | GP-Metadaten und Vorschlag | mindestens 2 Beobachtungen |
| Random | Warmstartgröße | Seed je Iteration | vollständige Batch-Aufteilung |
| Sobol | Warmstartgröße | Sequenzstartindex | vollständige Batch-Aufteilung |
| PSO | Warmstartgröße = Partikelzahl | Positionen, Geschwindigkeiten, pbest, gbest, RNG | mindestens 2 Partikel |
| Differential Evolution | Warmstartgröße = Population | Population, Fitness, Trials, RNG | mindestens 4 Individuen |

PSO und Differential Evolution benötigen jeweils alle Resultate des vorherigen Batches, bevor der nächste berechnet wird. Random und Sobol erzeugen ebenfalls ganze Batches. `total_runs - warm_start.sample_count` muss deshalb für alle außer Bayesian durch die Warmstartgröße teilbar sein.

## Bayesian Optimization im Detail

Bayesian Optimization (BO) modelliert die unbekannte Beziehung zwischen Parametern und `Ra` mit einem Gaußprozess (GP). Verwendet werden scikit-learn und der Kernel

\[
k(x,x') = C \cdot \operatorname{RBF}(x,x') + \operatorname{WhiteKernel}(x,x').
\]

Der GP normalisiert `y`, verwendet den Experiment-Seed als `random_state` und führt die konfigurierte Zahl `n_restarts_optimizer` aus. Alle nicht ignorierten abgeschlossenen Beobachtungen gehen ein; Penalty-Werte sind normale Beobachtungen mit `y=100`.

### Expected Improvement

Für Minimierung berechnet der Code mit bestem bisherigen Wert \(y_\min\), GP-Mittelwert \(\mu(x)\), Unsicherheit \(\sigma(x)\) und Offset \(\xi=\max(0{,}01\,\mathrm{std}(y),10^{-9})\):

\[
I(x)=y_\min-\mu(x)-\xi,
\qquad
EI(x)=I(x)\Phi(z)+\sigma(x)\phi(z),
\qquad
z=I(x)/\sigma(x).
\]

Bei praktisch null Unsicherheit wird EI auf null gesetzt. Eine SciPy-Differential-Evolution mit `maxiter=100`, `popsize=8` sucht zunächst das EI-Maximum im Einheitswürfel. Zusätzlich erzeugt ein LHS `candidate_count` Kandidaten. Der optimierte Punkt und die LHS-Punkte werden gemeinsam nach EI absteigend sortiert.

Bei `acquisition: "thompson"` wird für jeden Kandidaten stattdessen einmal `mean + std * Normal(0,1)` gezogen und aufsteigend sortiert, weil `Ra` minimiert wird.

### Auswahl des nächsten Punkts

`ParameterSpace.unique_parameters()` nimmt den bestgerankten noch nicht beobachteten, nach Quantisierung eindeutigen Satz. Reichen die Kandidaten nicht, ergänzt es bis zu mindestens 4096 LHS-Fallbackpunkte. Genau ein Vorschlag wird als Batch und danach als Run gespeichert.

## PSO und Differential Evolution

PSO startet die Partikel an den Warmstartpositionen, initialisiert Geschwindigkeiten in `[-0.05,0.05]` und aktualisiert sie aus Trägheit, persönlichem und globalem Bestwert. Geschwindigkeit wird auf `±max_velocity` begrenzt; bei Grenztreffern wird die betroffene Komponente auf null gesetzt.

Differential Evolution verwendet die Warmstartpunkte als Population. Für jedes Individuum werden drei andere ohne Zurücklegen gewählt; Mutation ist `r1 + differential_weight * (r2-r3)`. Binomiales Crossover erzwingt mindestens eine mutierte Dimension. Nach vollständiger Trial-Messung ersetzt nur ein besserer Trial sein Zielindividuum.

Beide speichern den vollständigen RNG- und Populationszustand als JSON-Checkpoint, sodass Resume dieselbe Evolution fortsetzt.

## Eine Iteration als Beispiel

Angenommen, zehn Warmstartläufe sind abgeschlossen und Bayesian ist konfiguriert:

1. `observations_from_store()` liest die zehn Run-JSONs und lässt ignorierte Fehlschläge weg.
2. Die Parameter werden normiert; die zehn `objective_value`-Werte bilden `y`.
3. Der GP wird neu angepasst.
4. Differential Evolution und LHS erzeugen/ranken Kandidaten.
5. Der beste noch nicht beobachtete quantisierte Punkt wird in `optimizer_state/bayesian_iteration_0000.json` festgeschrieben.
6. `runs/run_0011.json` wird mit Status `proposed` angelegt.
7. Der Simulator oder Hardwareadapter führt Run 11 aus.
8. Ein gültiges `Ra` schließt den Run ab; danach kann Iteration 1 entstehen.

Bricht der Prozess zwischen Schritt 5 und 7 ab, wird beim Resume der gespeicherte Punkt geladen und nicht neu optimiert.

## Messwertübergabe und ungültige Werte

`OrchestratorRunExecutor` akzeptiert nur einen `CycleResult` mit Status und Stufe `completed`, ohne Fehlertext sowie endlichen numerischen `Ra`- und `Rz`-Werten. Ungültige Messwerte werden als retry-fähige `result_validation`-Fehler klassifiziert.

Der darunterliegende Orchestrator wandelt jedoch zwei fehlgeschlagene QS-Aufrufe bereits in `Ra=Rz=100` plus Fehlertext um. Der Adapter erkennt den Fehlertext als `measurement_penalty`; dieser Satz wird über die Framework-Policy erneut versucht beziehungsweise endgültig als Penalty/Ignore gespeichert.

## Penalty, Ignore und Abbruch

- `penalty`: Nach maximal zwei automatischen vergleichbaren Versuchen wird `objective_value=100.0` gespeichert. Der Punkt beeinflusst alle Strategien als sehr schlechte Beobachtung.
- `ignore`: Der Run zählt zu `completed_runs`, hat aber keinen Zielfunktionswert und wird aus den Beobachtungen entfernt.
- Nach drei aufeinanderfolgenden endgültig fehlgeschlagenen Parametersätzen pausiert das Experiment, bis der Operator quittiert.
- `total_runs` zählt abgeschlossene Parametersätze einschließlich Penalty und Ignore, nicht physische Attempts.

Bekannte Einschränkung: Da ignorierte Punkte aus `observations_from_store()` entfernt werden, sieht die Duplikatprüfung sie ebenfalls nicht. Eine Strategie kann denselben ignorierten Parametersatz später erneut vorschlagen. Das sollte durch eine getrennte Menge aller bereits physischen Parameter behoben werden.

## Resume und Integrität

`--resume` öffnet exakt das konfigurierte Zielverzeichnis, prüft den Snapshot-Hash und rekonstruiert den Fortschritt aus den Run-Dateien. `--from-run` bestätigt die erwartete nächste Nummer; es überspringt keine Runs. Batch-Checkpoints verhindern eine Neuauslosung.

Noch nicht unterstützt:

- Import über nicht leere `paths.history_csvs`;
- CLI-Klassifikation eines nach Crash verbleibenden `running`-Runs;
- Ändern der Konfiguration während eines Experiments;
- QBC und die im Projektpitch genannten Modellvergleiche;
- automatische sichere Grenzen aus Drucker-/Materialmetadaten.

## Simulation versus Hardware

| Aspekt | Simulation | Hardware |
| --- | --- | --- |
| Executor | `SyntheticSurfaceExecutor` | `OrchestratorRunExecutor` |
| Sicherheitsflag | `--simulate` | `--confirm-hardware` |
| Erststart | direkt `--new` | zwingend `--new --preflight-only` |
| Ergebnis | deterministische künstliche `Ra/Rz` | QS-Messung |
| Artefakte | Store/Checkpoints/CSV | zusätzlich Profile, G-Code, Bilder, Hardware-CSV, Log |
| Nutzen | Logik, Resume, Strategie testen | reale Versuchsführung |

Weiter: [09 – Fehlerbehandlung](09_fehlerbehandlung.md)

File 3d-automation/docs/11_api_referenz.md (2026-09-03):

# 11 – API-Referenz

## Server und Basis-URL

Die FastAPI-Anwendung steht in `src/qs/api.py` und kombiniert QS und Kamera. Start auf dem Raspberry Pi aus `bachelor-3d-loop/3d-automation/`:

```bash
source .venv-pi/bin/activate
export PYTHONPATH="$PWD/src"
python -m uvicorn qs.api:app --host 0.0.0.0 --port 8000
```

Die Basis-URL ist aus Sicht des Hauptrechners der Wert von `QS_BASE_URL`, zum Beispiel `http://192.0.2.10:8000`. Standardmäßig verwendet der Kamera-Client dieselbe URL; `CAMERA_BASE_URL` kann sie überschreiben.

Im Projekt sind weder API-Authentifizierung noch TLS implementiert. Die API darf nur in einem kontrollierten Netz erreichbar sein. CORS-Konfiguration ist ebenfalls nicht vorhanden.

FastAPI stellt zusätzlich die generierten Oberflächen `/docs`, `/redoc` und das Schema `/openapi.json` bereit.

## Routenübersicht

| Methode | Route | Request | Erfolg | Wichtige Fehler |
| --- | --- | --- | --- | --- |
| `GET` | `/health` | – | 200 JSON | keine Geräteprüfung |
| `GET` | `/camera/health` | – | 200 JSON | 503 Abhängigkeit/Gerät fehlt |
| `POST` | `/camera/captures/{cycle_id}` | Path-Parameter | 200 JSON | 422 ID, 502 Aufnahme |
| `GET` | `/camera/captures/{cycle_id}` | Path-Parameter | 200 `image/jpeg` | 404 fehlt, 422 ID |
| `POST` | `/measurements` | kein Body | 200 JSON | 409, 422, 500, 502, 503, 504 |

`cycle_id` muss genau 32 Zeichen lang sein und dem regulären Ausdruck `^[0-9a-f]{32}$` entsprechen. Erwartet ist `uuid.uuid4().hex`, also Kleinbuchstaben und Ziffern ohne Bindestriche.

## `GET /health`

Prüft nur, ob der Webprozess antwortet. Serielle Schnittstelle, SJ-220 und Kamera werden nicht geprüft.

```bash
curl --fail --show-error "$QS_BASE_URL/health"
```

Antwort:

```json
{
  "status": "ok",
  "service": "qs-station"
}
```

Der `QualityStationClient.health()` hat 5 Sekunden Timeout, fordert erfolgreichen HTTP-Status und exakt `status: "ok"`.

## `GET /camera/health`

Prüft, ob `ffmpeg` und `v4l2-ctl` über `PATH` auffindbar sind und ob `CAMERA_DEVICE_PATH` existiert.

```bash
curl --fail --show-error "$QS_BASE_URL/camera/health"
```

Erfolg:

```json
{
  "status": "ok",
  "service": "camera",
  "device_path": "/dev/video0"
}
```

Fehler 503, Beispiel:

```json
{
  "detail": {
    "type": "missing_dependency",
    "message": "Missing camera command(s): ffmpeg"
  }
}
```

Alternativ ist `type` gleich `camera_unavailable`. Der Endpoint öffnet die Kamera nicht und testet keine Auflösung oder Controls. Der Kamera-Client verwendet 5 Sekunden Timeout.

## `POST /camera/captures/{cycle_id}`

Startet synchron genau eine Aufnahme. Request-Body und Query-Parameter gibt es nicht. Die API setzt die in [04 – Konfiguration](04_konfiguration.md) beschriebenen Controls, ruft `ffmpeg` auf und erwartet danach eine nicht leere JPEG-Datei.

```bash
CAMERA_CYCLE_ID="$(python -c 'import uuid; print(uuid.uuid4().hex)')"
curl --fail --show-error \
  -X POST \
  "$QS_BASE_URL/camera/captures/$CAMERA_CYCLE_ID"
```

Erfolg:

```json
{
  "status": "completed",
  "cycle_id": "0123456789abcdef0123456789abcdef",
  "filename": "0123456789abcdef0123456789abcdef.jpg"
}
```

| Status | `detail.type` | Bedeutung |
| --- | --- | --- |
| 422 | `invalid_cycle_id` | ID hat falsches Format |
| 502 | `camera_capture_error` | V4L2-/ffmpeg-/Dateifehler oder leere Ausgabe |

Der `CameraClient` verwendet 30 Sekunden Timeout, validiert Status, identische Cycle-ID und exakt den Dateinamen `<cycle_id>.jpg`. Anschließend lädt er die Datei automatisch herunter.

## `GET /camera/captures/{cycle_id}`

Liefert ein vorhandenes Bild als `image/jpeg` mit Dateinamen im `Content-Disposition`-Header.

```bash
curl --fail --show-error \
  "$QS_BASE_URL/camera/captures/$CAMERA_CYCLE_ID" \
  --output "$CAMERA_CYCLE_ID.jpg"
```

| Status | `detail.type` | Bedeutung |
| --- | --- | --- |
| 404 | `camera_capture_not_found` | keine nicht leere Datei für die ID |
| 422 | `invalid_cycle_id` | ID hat falsches Format |

Der Client-Download hat 30 Sekunden Timeout und schreibt zunächst `<name>.part`, dann wird atomar auf den endgültigen Dateinamen umbenannt. Eine leere HTTP-Nutzlast wird abgelehnt.

## `POST /measurements`

> **Physische Bewegung:** Dieser Aufruf öffnet `/dev/ttyUSB0` und startet eine SJ-220-Messung. Nur mit korrekt positioniertem Werkstück ausführen.

Es gibt keinen Request-Body. Die API fordert `Ra` und `Rz` an.

```bash
curl --fail --show-error \
  -X POST \
  "$QS_BASE_URL/measurements"
```

Erfolg, Zahlen nur Beispiel:

```json
{
  "status": "completed",
  "results": {
    "Ra": 4.152,
    "Rz": 22.5
  },
  "unit": "um",
  "duration_seconds": 12.34
}
```

`unit` ist die gemeinsame Einheit aller Results oder `null`, falls die Geräteantwort gemischte Einheiten enthält. Der HTTP-Client verwendet 90 Sekunden Timeout, akzeptiert nur `status: "completed"` und endliche numerische Werte für beide Felder. Er gibt intern `{"Ra": ..., "Rz": ...}` zurück.

### Fehlerantworten

FastAPI verpackt Details wie folgt:

```json
{
  "detail": {
    "type": "device_error",
    "code": "007",
    "message": "SJ-220 error 007: ..."
  }
}
```

| HTTP | `detail.type` | Exception im Server |
| --- | --- | --- |
| 409 | `port_in_use` | `SJ220PortInUseError` |
| 409 | `invalid_state` | `SJ220StateError` |
| 422 | `device_error` | `SJ220DeviceError`, zusätzlich `code` |
| 500 | `sj220_error` | sonstiger bekannter `SJ220Error` |
| 502 | `result_error` | `SJ220ResultError` |
| 502 | `protocol_error` | `SJ220ProtocolError` |
| 503 | `connection_error` | `SJ220ConnectionError` |
| 504 | `timeout` | `SJ220TimeoutError` |

Der Client selbst sendet einen Mess-POST nur einmal. `PrintOrchestrator` fängt jedoch jede Exception ab und ruft `measure()` ein zweites Mal auf. Das ist die aktuell wirksame Systemlogik; Details und Risiken stehen in [09 – Fehlerbehandlung](09_fehlerbehandlung.md).

## Zusammenspiel im Orchestrator

1. Im Preflight ruft der Orchestrator `/camera/health`, `/api/printer`, `/health` und den Roboter-Verbindungscheck auf.
2. Nach Druckstatus `FINISHED` sendet er `POST /camera/captures/{cycle_id}`.
3. `CameraClient` lädt sofort `GET /camera/captures/{cycle_id}` in das lokale Ergebnisverzeichnis.
4. Nach Abkühlung und Roboterpositionierung folgt `POST /measurements`.
5. Die Antwort wird als `Ra`/`Rz` in CycleResult und Persistenz überführt.

Die API kennt weder Experiment-ID, Run-Nummer noch Optimiereriteration. Die Korrelation geschieht ausschließlich über Cycle-ID und Dateien auf dem Hauptrechner.

## Nebenläufigkeit und Betrieb

FastAPI kann parallele Requests annehmen. Das SJ-220 schützt sich zusätzlich mit Thread-Lock und Prozess-Lockdatei; ein zweiter Prozess erhält einen Port-in-use-Fehler. Für Kameraaufnahmen existiert keine vergleichbare explizite Locklogik. Der Orchestrator arbeitet seriell und erzeugt normalerweise keine Parallelaufrufe.

Offene Betriebsaufgaben sind Authentifizierung/TLS, eine versionierte systemd-Unit, strukturierte Request-Logs, konfigurierbarer serieller Port und ein Health-Check, der optional den echten Gerätezustand prüft.

Weiter: [12 – Übergabe und offene Punkte](12_uebergabe_und_offene_punkte.md)

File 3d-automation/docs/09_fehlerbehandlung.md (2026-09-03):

# 09 – Fehlerbehandlung

## Erst sichern, dann fortsetzen

Bei jedem unbekannten Hardwarezustand gilt:

1. Keine weitere Automatik starten.
2. Druckerdisplay, Druckbett, Roboter, Greifer, QS und Taster physisch prüfen.
3. Bei akuter Kollisionsgefahr die vorgesehene sichere Abschaltung/Not-Aus verwenden.
4. Laufverzeichnis und Konsolen-/Dateilog sichern.
5. `failed_stage`, Run-Status, Attempt und Cycle-ID bestimmen.
6. Erst nach Behebung einen Preflight und den passenden Resume-Pfad ausführen.

## Troubleshooting-Matrix

„Automatisch?“ bezieht sich auf die aktuelle Optimierer-Hardwarelogik, nicht auf eine allgemeine technische Empfehlung.

| Sichtbarer Fehler / Situation | Komponente | Wahrscheinliche Ursache | Diagnose und Lösung | Automatisch? | Vollstopp / Fortsetzung |
| --- | --- | --- | --- | --- | --- |
| `Required environment variable ... is not set` | Startkonfiguration | `PRUSALINK_API_KEY` oder `QS_BASE_URL` fehlt | `config/end_to_end.env` prüfen und mit `set -a; source ...; set +a` laden; Wert nicht ausgeben | nein | vor Hardware beheben, normal neu starten |
| `No module named main/optimizer/...` | Python | falscher Startpfad oder `PYTHONPATH` fehlt | nach `3d-automation/` wechseln, venv aktivieren, `export PYTHONPATH="$PWD/src"` | ja, rein lokal | kein Hardwareversuch verbraucht |
| `No module named numpy/scipy/sklearn` | Optimierer | unvollständige Requirements installiert | `python -m pip install numpy scipy scikit-learn`, danach `pip check` | ja, vor Lauf | kein Hardwareversuch verbraucht |
| Slicer-Datei fehlt / Prozesscode ungleich 0 / leere Ausgabe | Slicer | falscher `PRUSASLICER_PATH`, Profil/STL ungültig, Slicerfehler | Pfade, Ausführungsrecht und manuellen `--version`-Aufruf prüfen; Slicer-Log lesen | ja; Stufe `slicing`, Attempt unverbraucht | Preflight wiederholen, dann derselbe Run |
| Drucker nicht erreichbar | PrusaLink | IP, Netz, API-Key oder PrusaLink falsch | Ping/Route und authentifiziertes `/api/printer` prüfen; Display kontrollieren | Preflight ja; später abhängig von Stufe | bei möglichem Druckstart erst manuell prüfen |
| Druckerstatus bleibt unerwartet / Statusfehlerlimit | Druckerüberwachung | Druck startete nicht, Netzunterbrechung, Firmwarezustand | `/api/v1/status` und Display vergleichen, Bett prüfen | Code: `waiting_for_print` retry-fähig | nach echter Statusklärung; automatische Einstufung ist ein Risiko |
| Drucktimeout | Druckprozess | Druck dauert > `PRINT_TIMEOUT_SECONDS`, Druck hängt | Display/Teil prüfen; Frist nicht blind erhöhen | Code: retry-fähig und Attempt verbraucht | laufenden Druck zuerst ausschließen |
| Spaghetti, Ablösung oder weggeflogenes Teil | Druck/Prozess | Haftung, Parameter, Geometrie | Sichtprüfung und Bild; Bett/Düse reinigen, Grenzen prüfen | nicht zuverlässig erkannt; möglicher späterer Retry | manueller Stopp empfohlen, Teil entfernen |
| Kamera-Health 503 | Kamera/Pi | `ffmpeg`/`v4l2-ctl` fehlt oder Gerätepfad nicht vorhanden | `/camera/health`, `which`, `ls -l`, V4L2-Formate prüfen | nein, Hardwareadapter klassifiziert Kamera terminal | Fehler beheben, manuell freigeben |
| Kamera-Capture 502 / leeres Bild | Kamera | unsupported Control/Format, Gerät belegt, ffmpeg-Fehler | API-Log, `v4l2-ctl -L`, Format und Auflösung prüfen | nein | vor Roboterhandling gestoppt; manuell prüfen/freigeben |
| Roboterverbindung fehlgeschlagen | Niryo | IP/Netz, Roboter aus, PyNiryo-Fehler | Preflight-`get_joints`, Netz und Roboteroberfläche prüfen | Preflight unverbraucht; im Zyklus terminal | Anlage prüfen, dann manueller Resume |
| Roboterkollision / Trackingfehler beim letzten Schub | QS-Roboter | Teil verklemmt oder Toleranz überschritten | Code führt feste 10-%-Recovery bis HOME aus; Vorrichtung/Teil danach prüfen | nein | trotz erfolgreicher Recovery terminal; manueller Resume |
| Roboterfehler an anderer Position | Roboter | Kollision, verlorenes Teil, falsche Lehre | sofort stoppen; aktuelle Pose und Mechanik sichern; kein generischer Rückzug implementiert | nein | vollständige Anlagenprüfung nötig |
| Teil verdreht oder verklemmt | QS-Mechanik | Ablage/Schub fehlgeschlagen | Sichtprüfung; Teil/Taster/Vorrichtung kontrollieren | nicht sensorisch erkannt | manuell stoppen und korrigieren |
| `/health` ok, Messung scheitert | SJ-220 | Health prüft nur Webdienst | direkte Messung nur mit Teil; Port, Kabel, Gerätestatus und Pi-Log prüfen | Messfehler im Orchestrator intern wiederholt | nach zwei Calls Framework-Retry/Penalty/Ignore |
| HTTP 409 `port_in_use` | SJ-220 | anderer Prozess hält Lock/Port oder ungültiger Gerätestatus | laufende API/CLI-Messung suchen; Lock nicht bei aktivem Prozess löschen | Orchestrator versucht zweiten POST | bei unklarem Detektorzustand stoppen |
| HTTP 503 `connection_error` | SJ-220 | `/dev/ttyUSB0`, Kabel, Rechte, Gerät aus | `ls -l /dev/ttyUSB0`, Gruppen, Kabel und Gerät prüfen | Orchestrator versucht zweiten POST | Ursache vor neuem Zyklus beseitigen |
| HTTP 504 `timeout` | SJ-220 | keine vollständige serielle Antwort/Messbewegung hängt | Detektorstatus, Kabel und Pi-Log prüfen | Orchestrator versucht zweiten POST | Detektorposition physisch prüfen |
| HTTP 422 `device_error` | SJ-220 | `NGnnn` vom Gerät | Code und Tabelle unten verwenden | nur `011/033` intern beim Lesen; sonst über Orchestrator | abhängig von Mechanik, meist Prüfung nötig |
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

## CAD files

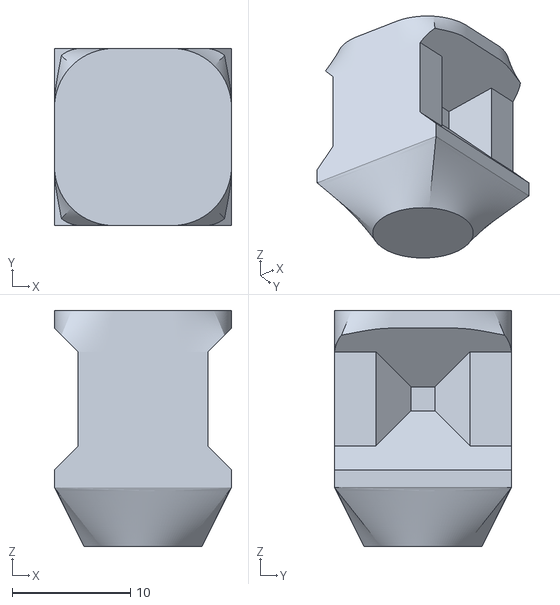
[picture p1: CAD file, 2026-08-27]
3d-automation/data/models/15x15_V2_rounded.stl
15.0 x 15.0 x 20.0

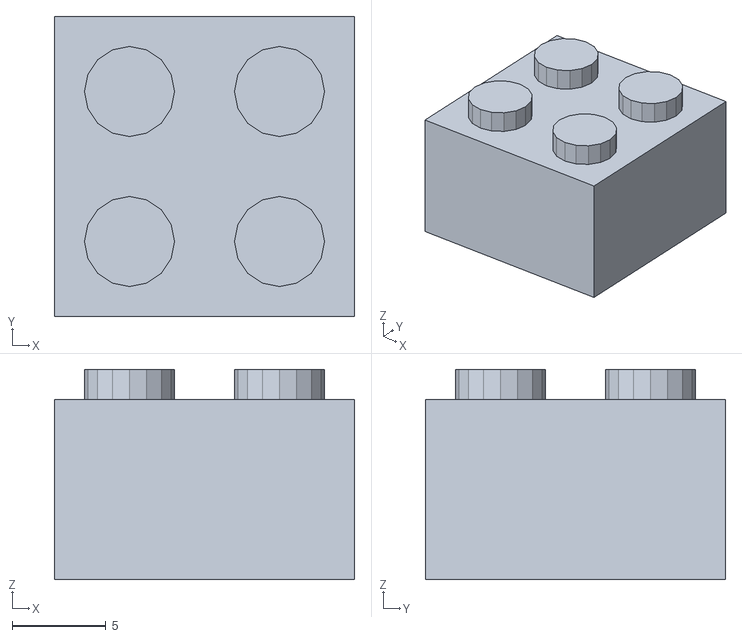
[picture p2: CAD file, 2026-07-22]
3d-automation/data/models/3003_Brick_2_x_2/3003.stl
16.0 x 16.0 x 11.2

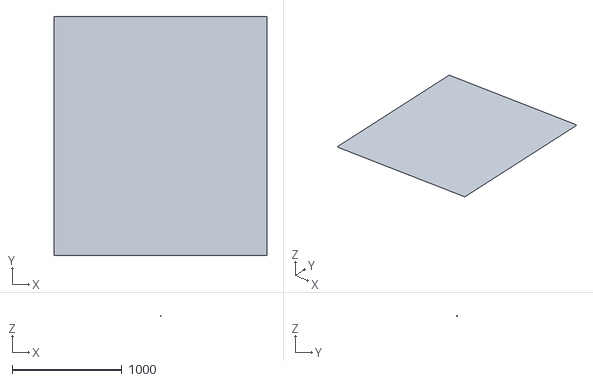
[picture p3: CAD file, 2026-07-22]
3d-automation/data/models/teamugstl.stl
1935.6 x 2174.2 x 2.12

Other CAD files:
3d-automation/data/models/Oberflächenmessung_Testkörper_MK1 (1).stl

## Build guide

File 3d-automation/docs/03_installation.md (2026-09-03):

# 03 – Installation

## Unterstützte Umgebung

Der Produktionspfad ist Linux-orientiert: PrusaSlicer ist standardmäßig als AppImage eingetragen, die Kamera verwendet `/dev/video*`, das Messgerät `/dev/ttyUSB0` und die Prozesssperre `/tmp/sj220_service.lock`. `scripts/install_system.sh` richtet die aktuelle Software für den Hauptrechner, den Raspberry Pi oder beide Rollen ein. Das alte `scripts/setup.bat` legt dagegen nur zwei Verzeichnisse an und ist kein vollständiger Installer.

Eine Python-Version ist im Repository nicht formal festgelegt. Aus der Syntax folgt Python **3.10 oder neuer**; Analyse und Tests dieser Übergabe liefen mit Python **3.12.3**. Für reproduzierbaren Betrieb sollte das Projekt künftig eine Version in `pyproject.toml` oder einer vergleichbaren Datei festschreiben.

## 1. Repository beziehen

Die Remote-URL ist in der lokalen Git-Konfiguration als `origin` hinterlegt.

**Arbeitsverzeichnis: Elternverzeichnis des künftigen Projekts**

```bash
git clone https://github.com/ali2644/bachelor-3d-loop.git bachelor-3d-loop
cd bachelor-3d-loop
git switch feature/optimizer-framework-integration
```

Der bei der Dokumentation analysierte Stand war Commit `29f11b9`. Vor einer Übergabe ist zu prüfen, ob Branch und Commit im Remote vorhanden und weiterhin freigegeben sind; ein zukünftiger Checkout darf einen neueren, freigegebenen Stand verwenden.

## 2. Empfohlene Installation mit dem Skript

Das Installationsskript erkennt seinen Projektpfad selbst und kann deshalb aus jedem Arbeitsverzeichnis aufgerufen werden. Es unterstützt drei Rollen:

| Rolle | Installierter Softwareumfang |
| --- | --- |
| `main` | End-to-End-Anwendung, Hardwareclients, Optimierer, NumPy, SciPy und scikit-learn |
| `pi` | FastAPI, Uvicorn und PySerial für QS und Kamera; keine unnötige Roboter- oder Optimiererbibliothek |
| `all` | beide Umfänge auf demselben Linux-System |

### Hauptrechner

**Arbeitsverzeichnis: `bachelor-3d-loop/`**

```bash
chmod +x 3d-automation/scripts/install_system.sh
./3d-automation/scripts/install_system.sh \
  --role main \
  --install-system-packages
```

Der Schalter `--install-system-packages` nutzt `apt` und ist für Debian, Ubuntu und Raspberry Pi OS gedacht. Auf einem bereits vorbereiteten oder nicht apt-basierten System wird er weggelassen. Standardmäßig entsteht die virtuelle Umgebung als `.venv` im Repository-Root.

### Raspberry Pi

**Arbeitsverzeichnis: `bachelor-3d-loop/` auf dem Pi**

```bash
chmod +x 3d-automation/scripts/install_system.sh
./3d-automation/scripts/install_system.sh \
  --role pi \
  --install-system-packages
```

Für einen automatischen API-Start kann das Skript zusätzlich eine konkrete systemd-Unit erzeugen, installieren und starten:

```bash
./3d-automation/scripts/install_system.sh \
  --role pi \
  --install-system-packages \
  --install-service \
  --service-user pi
```

`--install-service` ist absichtlich explizit: Nur dieser Schalter startet einen Prozess. Der Dienst führt Uvicorn aus, löst beim Start aber keine Messung und keine Kameraaufnahme aus. Die Unit verwendet absolute Pfade, `config/qs_station.env`, `Restart=on-failure` und `NoNewPrivileges=true`. Der angegebene Dienstbenutzer muss die virtuelle Umgebung und den Quellcode lesen sowie `data/camera_images` beschreiben können; der Installer prüft das vor der Unit-Installation. Am einfachsten wird das Skript als genau dieser normale Benutzer ausgeführt und nur seine Systemschritte werden intern über `sudo` erhöht.

### Wichtige Eigenschaften und Optionen

- Vorhandene `config/end_to_end.env` und `config/qs_station.env` werden nie überschrieben.
- Lokale Env-Dateien werden mit Modus `0600` angelegt und von Git ignoriert.
- Die Installation führt keinen Druck, keine Roboterbewegung, keine Messung und keine Kameraaufnahme aus.
- Mit `--venv <Pfad>` und `--python <Interpreter>` lassen sich Umgebung und Python wählen.
- `--check-only` prüft eine bestehende Installation ohne Installationsänderung.
- `--prusa-slicer <Pfad>` prüft eine abweichende PrusaSlicer-Datei, lädt sie aber nicht herunter.
- `--help` zeigt alle Optionen und Beispiele.

Beispiel für eine reine Prüfung:

```bash
./3d-automation/scripts/install_system.sh --role main --check-only
./3d-automation/scripts/install_system.sh --role pi --check-only
```

Warnungen wegen nicht angeschlossener `/dev/video0`- oder `/dev/ttyUSB0`-Geräte sowie eines fehlenden PrusaSlicers beenden die Softwareprüfung nicht. Fehlende Python-Module oder inkonsistente Pakete führen dagegen zu einem Fehlercode.

## 3. Manuelle Alternative: Hauptrechner einrichten

### Virtuelle Umgebung und Python-Pakete

**Arbeitsverzeichnis: `bachelor-3d-loop/`**

```bash
python3.12 -m venv .venv
source .venv/bin/activate
python -m pip install --upgrade pip
python -m pip install -r 3d-automation/requirements.txt
python -m pip install numpy scipy scikit-learn
```

`3d-automation/requirements.txt` enthält FastAPI, Uvicorn, PyNiryo, PySerial und Requests. Die vom Optimierer tatsächlich importierten Pakete NumPy, SciPy und scikit-learn fehlen dort; der zusätzliche Installationsbefehl ist deshalb derzeit erforderlich. Die Root-Datei `requirements.txt` ist eine ältere, für die aktuelle Anwendung unvollständige HTTP-Abhängigkeitsliste. `PrusaLinkPy` steht zwar dort, der aktuelle `PrusaLinkService` verwendet jedoch direkt `requests`.

### Python-Module erreichbar machen

**Arbeitsverzeichnis: `bachelor-3d-loop/3d-automation/`**

```bash
source ../.venv/bin/activate
export PYTHONPATH="$PWD/src"
python -m main --help
```

Das Projekt ist nicht als installierbares Python-Paket konfiguriert. `PYTHONPATH` muss daher in jeder neuen Shell gesetzt werden. Ein falsches Arbeitsverzeichnis führt typischerweise zu `No module named main` oder zu falsch aufgelösten relativen Kamera-Pfaden.

## 4. PrusaSlicer installieren

Der Code erwartet standardmäßig:

```text
~/apps/prusaslicer/PrusaSlicer-2.9.1-x86_64.AppImage
```

Eine andere ausführbare Datei wird über `PRUSASLICER_PATH` konfiguriert. Installation und Downloadquelle sind im Repository nicht automatisiert.

**Arbeitsverzeichnis: beliebig; Beispielpfad aus dem Code**

```bash
mkdir -p "$HOME/apps/prusaslicer"
chmod +x "$HOME/apps/prusaslicer/PrusaSlicer-2.9.1-x86_64.AppImage"
"$HOME/apps/prusaslicer/PrusaSlicer-2.9.1-x86_64.AppImage" --version
```

Der Download der Datei muss vorher aus einer vertrauenswürdigen, projektspezifisch freigegebenen Quelle erfolgen. Der Code dokumentiert keinen Download-Link und keine Prüfsumme.

Der spätere Slicer-Aufruf lautet sinngemäß:

```bash
"$PRUSASLICER_PATH" -g --load <PROFIL.ini> --center 90,45 <MODELL.stl> --output <AUSGABE.gcode>
```

## 5. Hauptrechner konfigurieren

**Arbeitsverzeichnis: `bachelor-3d-loop/3d-automation/`**

```bash
cp config/end_to_end.env.example config/end_to_end.env
chmod 600 config/end_to_end.env
```

Danach nur `config/end_to_end.env` lokal bearbeiten. Die Datei ist durch `.gitignore` ausgeschlossen und darf wegen des PrusaLink-Schlüssels nicht committet werden.

```bash
set -a
source config/end_to_end.env
set +a
```

Alle Felder erklärt [04 – Konfiguration](04_konfiguration.md).

## 6. Manuelle Alternative: Raspberry Pi 5 einrichten

Die folgende Paketinstallation ist eine Debian-/Raspberry-Pi-OS-Anleitung, abgeleitet aus den verwendeten Befehlen. Eine Distribution oder ein fertiges Deployment ist im Repository nicht festgeschrieben.

**Arbeitsverzeichnis: beliebig auf dem Raspberry Pi**

```bash
sudo apt update
sudo apt install python3-venv python3-pip ffmpeg v4l-utils
```

Den Projektstand auf den Pi übertragen oder dort klonen. Danach:

**Arbeitsverzeichnis: `bachelor-3d-loop/3d-automation/` auf dem Pi**

```bash
python3 -m venv .venv-pi
source .venv-pi/bin/activate
python -m pip install --upgrade pip
python -m pip install -r requirements.txt
export PYTHONPATH="$PWD/src"
```

Für QS und Kamera sind aus der Datei mindestens `fastapi`, `uvicorn`, `pyserial` sowie `ffmpeg` und `v4l2-ctl` relevant. PyNiryo wird nur auf einem Rechner benötigt, der den Roboterclient ausführt.

### USB- und Kamera-Geräte prüfen

**Arbeitsverzeichnis: beliebig auf dem Pi**

```bash
ls -l /dev/ttyUSB0
ls -l /dev/video0
v4l2-ctl --list-devices
v4l2-ctl -d /dev/video0 --list-formats-ext
```

Wenn der Benutzer nicht auf die serielle Schnittstelle zugreifen darf, ist auf Debian-artigen Systemen häufig die Gruppe `dialout` relevant:

```bash
sudo usermod -aG dialout "$USER"
```

Danach ab- und wieder anmelden. Die tatsächlich benötigte Gruppe ist mit `ls -l /dev/ttyUSB0` zu prüfen; sie ist nicht im Repository festgelegt.

### API im Vordergrund starten

**Arbeitsverzeichnis: `bachelor-3d-loop/3d-automation/` auf dem Pi**

```bash
source .venv-pi/bin/activate
export PYTHONPATH="$PWD/src"
export CAMERA_DEVICE_PATH=/dev/video0
export CAMERA_OUTPUT_DIR="$PWD/data/camera_images"
export CAMERA_WIDTH=1920
export CAMERA_HEIGHT=1080
export CAMERA_PIXEL_FORMAT=mjpeg
python -m uvicorn qs.api:app --host 0.0.0.0 --port 8000
```

Alternativ zum Vordergrundstart erzeugt `scripts/install_system.sh --role pi --install-service --service-user <Benutzer>` eine installationsspezifische `/etc/systemd/system/qs-station.service`. Es liegt bewusst keine Unit mit fest codierten Projektpfaden im Repository; der Installer setzt die absoluten Pfade des jeweiligen Zielsystems ein.

## 7. Installation validieren

### Hauptrechner, ohne Hardwarebewegung

**Arbeitsverzeichnis: `bachelor-3d-loop/3d-automation/`**

```bash
source ../.venv/bin/activate
export PYTHONPATH="$PWD/src"
python -m compileall -q src tests
python -m pip check
python -m optimizer.config config/optimizer_config.example.json --check-input-files
python -m optimizer.warm_start config/optimizer_config.example.json
```

`compileall` bleibt ohne Ausgabe, wenn alle Dateien syntaktisch kompiliert wurden. `pip check` soll `No broken requirements found.` melden. Die Konfigurationsprüfung gibt eine normalisierte JSON-Struktur aus; der Warmstart zeigt die geplanten Punkte, ohne Zustand oder Hardware zu verändern.

### Netzwerk vom Hauptrechner

Ersetzen Sie nur den Pi-Platzhalter; der Drucker-Standard stammt aus `main.py`.

```bash
curl --fail --show-error http://<RASPBERRY-PI-IP>:8000/health
curl --fail --show-error http://<RASPBERRY-PI-IP>:8000/camera/health
curl --fail --show-error http://10.8.170.57/api/printer
```

Der letzte Aufruf kann abhängig von PrusaLink eine Authentifizierungsantwort liefern. Der echte Client sendet `X-Api-Key`; Schlüssel gehören nicht in Shell-Historie oder Dokumentation.

### Tests

```bash
python -m unittest discover -s tests -v
```

Der aktuelle bekannte Stand ist in [10 – Tests und Entwicklung](10_tests_und_entwicklung.md) dokumentiert. Dieser Befehl bewegt nach aktuellem Testaufbau keine Hardware; die Clients werden gemockt.

Weiter: [04 – Konfiguration](04_konfiguration.md)

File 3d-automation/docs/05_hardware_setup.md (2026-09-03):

# 05 – Hardware-Setup

> **Gefahr von Sach- und Personenschäden:** Positionswerte sind an eine konkrete mechanische Anordnung gebunden. Nach Umbau, Transport, Werkzeugwechsel oder Firmwareänderung zuerst mit reduzierter Geschwindigkeit, freiem Arbeitsraum und erreichbarem Not-Aus validieren. Direkte Roboterskripte können sich schon beim Start kalibrieren und bewegen.

## Gemeinsame Voraussetzungen

Vor jeder Hardwareprüfung:

1. Drucker, Roboter, Raspberry Pi, SJ-220 und Kamera einschalten.
2. Hauptrechner, Drucker, Roboter und Pi in ein erreichbares Netz bringen.
3. Mechanische Befestigung von Drucker, QS-Station, Greifer, Taster und Kamera prüfen.
4. Druckerbett und komplette Roboterbahn räumen.
5. Not-Aus beziehungsweise sichere Abschaltmöglichkeit lokalisieren.
6. Erst Netzwerk- und Health-Checks, dann `preflight`, danach einzelne Mechanik und zuletzt einen Gesamtzyklus ausführen.

## Prusa MINI/MINI+

### Aufgabe und Verbindung

Der Drucker erhält den von PrusaSlicer erzeugten G-Code über PrusaLink. Der Hauptrechner baut eine unverschlüsselte HTTP-Verbindung zu `http://<PRINTER_IP>` auf; ein besonderer Port ist nicht konfiguriert, daher gilt Port 80.

Der Code bezeichnet das Zielgerät allgemein als Prusa-Drucker; das Basisprofil enthält `printer_model = MINIIS` und einen MINI-Modellcheck. Ob die konkrete Maschine MINI oder MINI+ ist, muss am Gerät bestätigt werden.

### Voraussetzungen und Prüfung

- PrusaLink muss aktiviert und im Netz erreichbar sein.
- Ein gültiger API-Key muss lokal als `PRUSALINK_API_KEY` gesetzt sein.
- Der vom Profil erwartete Düsendurchmesser, Werkstoff und Druckerzustand müssen zur Maschine passen.
- Der USB-Zielpfad aus `REMOTE_GCODE_PATH` muss beschreibbar sein.

**Arbeitsverzeichnis: `3d-automation/`, keine Bewegung**

```bash
curl --fail --show-error "http://${PRINTER_IP:-10.8.170.57}/api/printer" \
  -H "X-Api-Key: $PRUSALINK_API_KEY"
```

Der Orchestrator akzeptiert beim Preflight nur die Druckerzustände `IDLE` oder `FINISHED`. Er wartet beim realen Lauf zunächst auf `PRINTING` oder `PAUSED` und danach auf `FINISHED`.

### Verwendete PrusaLink-Aufrufe

| Zweck | Methode und Pfad | Besonderheit |
| --- | --- | --- |
| Verbindung | `GET /api/printer` | `X-Api-Key`, 10-s-Request-Timeout |
| Status | `GET /api/v1/status` | Fehler werden begrenzt toleriert |
| Upload + Start | `PUT /api/v1/files/usb/{REMOTE_GCODE_PATH}` | `Overwrite: ?1`, `Print-After-Upload: ?1`; 10 s Connect/300 s Read |

Bei unerwartetem Druckerzustand nicht sofort denselben G-Code neu starten. Zuerst am Display prüfen, ob ein Druck noch läuft oder ein Teil auf dem Bett liegt.

## PrusaLink als Softwarekomponente

`src/printer/prusalink_service.py` verwendet `requests` direkt. Es gibt keinen Discovery-Mechanismus und keine TLS-Konfiguration. IP und Schlüssel müssen daher stimmen; die QS-API darf nicht irrtümlich als Druckerziel eingetragen werden.

Der Remote-Pfad wird auf gefährliche Bestandteile geprüft. Absolute Pfade, `..`, leere Segmente und Query-/Fragmentzeichen sind nicht als normaler Dateiname gedacht. Der Default ist `FOLDER/demo.gcode`.

Nach einem Netzwerkfehler:

1. Druckerdisplay und Bett physisch prüfen.
2. `GET /api/v1/status` erneut abfragen.
3. Nur wenn kein Druck aktiv ist entscheiden, ob ein neuer Versuch sicher ist.
4. Im Optimierer ausschließlich den vom Store angebotenen Retry-/Resume-Pfad verwenden.

## Niryo Ned2

### Verbindung und Initialisierung

Der Hauptrechner verbindet sich über PyNiryo mit `ROBOT_IP`, standardmäßig `10.8.170.41`. Port und Transportdetails verwaltet PyNiryo; im Projekt ist kein eigener Roboterport angegeben. `RobotService.initialize()` führt automatische Kalibrierung, Werkzeugaktualisierung, Löschen des Kollisionsflags und eine maximale Armgeschwindigkeit von 50 % aus.

Der Preflight ruft nur `get_joints()` auf und kalibriert oder bewegt den Arm nicht.

### Tatsächliche Bewegungsfolge

Die verbindlichen Wegpunkte stehen in `src/robot/robot_positions.py`, die Reihenfolge in `src/robot/robot_service.py`:

1. `HOME`, Greifer schließen.
2. `PRINTER_SAFE`, Greifer öffnen, `PRINTER_PICK`.
3. Zweistufig greifen, dann `PRINTER_BREAK_OFF_1`, `PRINTER_BREAK_OFF`, `PRINTER_OUTSIDE`.
4. Über `TRANSFER_CLEARANCE` zu `QS_SAFE` und `QS_PART_RELEASE`; Teil ablegen.
5. Über `QS_ALIGNMENT_ORIENTATION`, langsam `QS_ALIGNMENT_CONTACT` → `QS_ALIGNMENT_END` → `QS_ALIGNMENT_CONTACT`, dann `QS_ALIGNMENT_RETREAT`.
6. `QS_FINAL_PUSH_CONTACT`, langsam `QS_FINAL_PUSH_TARGET`, zurück zu Kontakt und `QS_SAFE`.
7. `QS_LIFT_LEVER_GRIP`, drei Sekunden warten, langsam `QS_PART_UNDER_PROBE`, zurück über Greifpunkt nach `QS_SAFE`.
8. Nach der Messung `QS_LIFT_LEVER_APPROACH` → `QS_LIFT_LEVER_END` → Approach → `QS_SAFE`.
9. `QS_PART_SHIFT_APPROACH` → `QS_PART_SHIFT_END` → Approach → `QS_SAFE` → `HOME`.

Langsame Schubbewegungen laufen mit 20 %, die Kollisions-Recovery mit 10 %. Die Gelenkwerte werden hier bewusst nicht dupliziert; nur `robot_positions.py` soll für Änderungen editiert werden.

### Kollisionsverhalten

Nur beim letzten Schub werden Meldungen mit `collision` oder `motor not able to follow` als erwarteter Sonderfall behandelt. Dann löscht der Code das Kollisionsflag und fährt die fest gelehrte Recovery über `QS_FINAL_PUSH_CONTACT`, `QS_SAFE`, `QS_SAFE_RECOVERY`, `QS_RECOVERY`, erneut Kontakt, `QS_RECOVERY_CLEAR_PART`, `QS_SAFE`, `HOME`. Der Orchestrator bricht danach vor der Messung ab.

Alle anderen Roboterfehler werden weitergereicht; es gibt dafür keine allgemeine automatische Rückzugsbahn. Anlage sichern, Position feststellen und erst nach physischer Korrektur einen manuellen Resume vorbereiten.

Die generierten/älteren Positionsdokumente sind teilweise veraltet und dürfen die Service-Reihenfolge nicht ersetzen.

## Mitutoyo SJ-220

### Verbindung

Das Messgerät ist über RS-232C/USB am Raspberry Pi angeschlossen. Die API verwendet fest:

| Einstellung | Wert aus `SJ220Service` / API |
| --- | --- |
| Gerät | `/dev/ttyUSB0` |
| Baud | `38400` |
| Datenformat | 8 Datenbits, keine Parität, 1 Stoppbit |
| Flusssteuerung | RTS/CTS ein; DSR/DTR und XON/XOFF aus |
| Lese-/Schreibtimeout | je 3 s |
| Messfrist / Startfrist | 60 s / 30 s |
| Polling | 0,25 s |
| temporäre Read-Retries | 5, nur Codes `011` und `033` |
| Prozesssperre | `/tmp/sj220_service.lock` |

Verwendete Kommandos sind `RDSTU00` (Status), `RDPSA` (Detektorposition), `CTSTA` (Start), `RDPAR` (Parameteranzahl) und `RDRES02,NN,00` (Ergebnis). Befehle enden mit Carriage Return.

### Sicherer Verbindungstest

`/health` testet **nicht** das serielle Gerät. Eine direkte Messung bewegt den Detektor und darf nur mit korrekt positioniertem Testkörper erfolgen.

**Arbeitsverzeichnis: `3d-automation/` auf dem Pi; physische Messbewegung**

```bash
source .venv-pi/bin/activate
export PYTHONPATH="$PWD/src"
python -m qs.run_sj220
```

Erfolg: Ausgabe enthält `Messung erfolgreich`, `Ra`, `Rz` und Messdauer; Exitcode 0. Typisierte Fehler verwenden Exitcodes 2 bis 8, Abbruch per Tastatur 130.

Bei Fehler `007` versucht `SJ220Service.measure()` intern eine zusätzliche Messung und meldet den Fehler trotzdem weiter. Deshalb erst Werkstück, Messbereich und Detektorposition prüfen; nicht blind erneut auslösen.

## Raspberry Pi 5 und QS-API

Der Pi hostet `qs.api:app`. Die Anwendung serialisiert konkurrierende SJ-Zugriffe über Lockdatei und öffnet den Port pro HTTP-Messung. Die API bietet keine im Projekt implementierte Authentifizierung; Port 8000 deshalb nur in einem kontrollierten lokalen Netz freigeben.

**Arbeitsverzeichnis: `3d-automation/` auf dem Pi**

```bash
source .venv-pi/bin/activate
export PYTHONPATH="$PWD/src"
python -m uvicorn qs.api:app --host 0.0.0.0 --port 8000
```

Es existiert noch kein versionierter systemd-Service. Nach Prozessabbruch wird der serielle Kontext normalerweise geschlossen; bei einem harten Abbruch sind Portbelegung und `/tmp/sj220_service.lock` zu diagnostizieren. Die Lockdatei nicht löschen, solange ein Messprozess laufen könnte.

## Kamera / V4L2

Die Kamera hängt standardmäßig an `/dev/video0`. Vor dem API-Start müssen `v4l2-ctl` und `ffmpeg` im `PATH` liegen. Der Health-Endpunkt prüft genau diese Programme und die Existenz des Gerätepfads.

Für jede Aufnahme setzt der Code standardmäßig Auto-Exposure `1`, Belichtungszeit `220`, Gain `64`, Helligkeit `-30`, Kontrast `80`, Gamma `300`, Schärfe `80`, automatischen Weißabgleich `0`, Weißabgleich `3800`, Sättigung `30` und Backlight-Kompensation `0`. Nicht jede Kamera muss diese Controls unterstützen; ein fehlender Control führt zu einem Aufnahmefehler.

**Arbeitsverzeichnis: beliebig auf dem Pi, keine Roboterbewegung**

```bash
v4l2-ctl --list-devices
v4l2-ctl -d /dev/video0 -L
v4l2-ctl -d /dev/video0 --list-formats-ext
curl --fail --show-error http://127.0.0.1:8000/camera/health
```

Die API-Aufnahme ist in [11 – API-Referenz](11_api_referenz.md) beschrieben. `show_live()` in `camera_ctrl.py` baut seine Control-Zeichenfolge derzeit aus den explizit übergebenen Controls statt aus den zusammengeführten Defaults; das Livebild ist nicht Teil des Orchestratorpfads, aber diese Abweichung sollte vor Nutzung korrigiert werden.

## QS-Station als Gesamtsystem

Die QS-Station verbindet Ablage, horizontale Ausrichtung, Endschub, Hebemechanik, Tastermessung und Ausschub. Software-Health allein kann folgende physische Fehler nicht erkennen: verdrehter Testkörper, Teil außerhalb der Aufnahme, verklemmter Hebel, falsche Tasterhöhe oder ein vom Druckbett weggeflogenes Teil.

### Sichere Wiederherstellung

1. Automatik stoppen und Bewegungszustand an allen Geräten prüfen.
2. Roboter nicht von Hand gegen aktive Motoren bewegen; Herstellerverfahren beachten.
3. Testkörper und lose Teile entfernen, Taster und Vorrichtung auf Schäden prüfen.
4. Roboter über einen sicheren, vor Ort bestätigten Weg in eine bekannte Stellung bringen.
5. Verbindungen und Health-Endpunkte erneut prüfen.
6. `preflight-only` ausführen.
7. Terminalen Optimiererfehler erst danach mit `--resume-after-manual-intervention --from-run N --preflight-only` freigeben.

Weiter: [06 – Bedienung](06_bedienung.md)

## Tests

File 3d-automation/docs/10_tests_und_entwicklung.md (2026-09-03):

# 10 – Tests und Entwicklung

## Testwerkzeug und Aufbau

Die Tests verwenden Python `unittest`, `unittest.mock`, temporäre Verzeichnisse und kleine Fake-Hardwareadapter. Es gibt keine `pytest`-, Coverage-, Lint-, Formatter- oder CI-Konfiguration im Repository.

| Bereich | Testdateien | Abdeckung |
| --- | --- | --- |
| Orchestrator | `test_orchestrator.py`, `test_orchestrator_camera.py` | Reihenfolge, Status, Mess-Retry/Penalty, Kamera und Robot-Recovery |
| Druck | `test_print_parameters.py`, `test_slicer_service.py`, `test_prusalink_service.py` | Profilmapping, Domänen, Prozessaufruf und HTTP |
| QS/Kamera | `test_qs_api_client.py`, `test_camera_api.py`, `test_camera_client.py` | Payloads, Statuscodes, Download und Validierung |
| statischer Versuch | `test_experiment_plan.py`, `test_experiment_runner.py`, `test_csv_cycle_recorder.py`, `test_main.py` | Plan, Auswahl/Resume, Speicherung und CLI |
| Optimierer | `test_optimizer_config.py`, `test_warm_start.py`, `test_strategies.py`, `test_experiment_store.py`, `test_framework_runner.py` | Schema, Reproduzierbarkeit, alle Strategien, Persistenz, Retry/Pause |
| Hardwareadapter | `test_hardware_executor.py`, `test_hardware_cli.py` | Stufenklassifikation, Sicherheitsflags, Preflight-Receipt und Resume |
| veraltet | `test_bayesian_optimizer.py` | erwartet entferntes Legacy-Modul und läuft aktuell nicht |

Die Tests sind Unit- und dateibasierte Integrationstests. Sie ersetzen HTTP, Subprozesse und Roboter durch Mocks/Fakes. Es gibt keine automatisierten End-to-End-Tests gegen echte Geräte.

## Vollständiger Testlauf

**Arbeitsverzeichnis: `bachelor-3d-loop/3d-automation/`**

```bash
source ../.venv/bin/activate
export PYTHONPATH="$PWD/src"
python -m unittest discover -s tests -v
```

Für die Tests werden keine Hardware-Env-Werte benötigt. Der bei der Übergabe ausgeführte Lauf fand 130 Tests: 129 liefen erfolgreich, ein Testmodul scheiterte beim Import:

```text
ModuleNotFoundError: No module named 'optimizer.bayesian_optimizer'
```

Ursache ist `tests/test_bayesian_optimizer.py`, das die entfernte Legacy-API `BayesianOptimizer` und `read_optimization_history` importiert. Die aktuelle Implementierung liegt in `optimizer.strategies.BayesianStrategy` und verwendet `ExperimentStore`; die aktuellen Strategie-/Frameworktests decken diesen Weg ab. Der Test sollte migriert oder nach nachvollziehbarer Entscheidung entfernt werden.

## Sichere Zusatzprüfungen

```bash
python -m compileall -q src tests
python -m pip check
python -m optimizer.config config/optimizer_config.example.json --check-input-files
python -m optimizer.warm_start config/optimizer_config.example.json
```

Bei dieser Übergabe waren Kompilierung und `pip check` erfolgreich; Config und Warmstart liefen erfolgreich.

## Simulation als Integrationstest

Eine Simulation prüft Store, Vorschlagslogik, Checkpoints, CSV-Export und Resume gemeinsam. Sie kontaktiert keine Geräte.

1. `config/optimizer_config.simulation.json` kopieren.
2. In der Kopie einen noch nicht vorhandenen `paths.output_directory` setzen.
3. Einen begrenzten Erstlauf und Resume ausführen:

```bash
python -m optimizer.framework_runner \
  config/optimizer_config.simulation.local.json \
  --simulate --new --max-runs 2

python -m optimizer.framework_runner \
  config/optimizer_config.simulation.local.json \
  --simulate --resume --from-run 3 --max-runs 2
```

Der im Rahmen dieser Dokumentation ausgeführte frische Smoke-Test schloss Runs 1–2 und nach Resume 3–4 erfolgreich ab.

## Einzelne Tests ausführen

Beispiele, jeweils aus `3d-automation/`:

```bash
python -m unittest -v tests/test_orchestrator.py
python -m unittest -v tests/test_hardware_cli.py
python -m unittest -v tests/test_strategies.py
```

Ein erfolgreicher Lauf endet mit `OK`. `FAILED (failures=N)` bedeutet eine nicht erfüllte Assertion; `FAILED (errors=N)` meist eine Exception in Setup oder Testcode. Der aktuelle Legacy-Import ist ein `error`, kein nachgewiesener Fehler der neuen Strategie.

## Mocking-Strategie

`PrintOrchestrator` erwartet protokollartige Abhängigkeiten für Slicer, Drucker, Roboterfactory, QS, Recorder und Kamera. Tests implementieren nur die tatsächlich aufgerufenen Methoden und protokollieren Reihenfolge/Argumente. HTTP-Clients mocken `requests.Session`; Slicer-Tests mocken `subprocess.run`. `HardwareExecutorTest` stellt einen Fake-Orchestrator bereit, `HardwareCliTest` einen Builder, der nie echte Hardware konstruiert.

Neue Tests dürfen keine Standard-IP kontaktieren. Fakes sollten einen Fehler gezielt mit derselben `CycleStage` auslösen, die der Produktionsadapter verwendet.

## Hardwaretests

Es gibt keine automatisierte Hardware-Test-Suite. Vor Ort sollte eine versionierte Abnahmematrix geführt werden:

1. Slicer mit Referenz-STL und Profil.
2. PrusaLink Health, Upload ohne unbeabsichtigten Druck und anschließend kontrollierter Druck.
3. Roboter-`get_joints` ohne Bewegung.
4. Jede gelehrte Teilsequenz bei reduzierter Geschwindigkeit und leerer Vorrichtung.
5. Kamera-Health, Aufnahme und Download.
6. SJ-220 mit Referenznormal und erwarteten Ra/Rz-Bereichen.
7. Einzelzyklus, zwei statische Zyklen und ein Optimierer-Einzellauf.
8. Geplante Fehlerfälle: Netzunterbrechung, Kameraausfall und kontrollierter manueller Stopp.

Ergebnisse, Anlagenkonfiguration, Firmwareversionen und Freigabegrenzen sind im Repository derzeit nicht strukturiert erfasst.

## Neue Hardwarekomponente hinzufügen

1. Kleine Schnittstelle/Protocol mit zeitlich begrenzten Methoden definieren.
2. Adapter in einem eigenen Modul implementieren; Verbindung, Close und Timeout explizit behandeln.
3. Im `main.build_orchestrator()` verdrahten, ohne globale Initialisierung beim Import.
4. Neue `CycleStage` beziehungsweise Fehlerklassifikation bewusst festlegen: vorphysisch, vergleichbar oder terminal.
5. Orchestrator-Reihenfolge mit Fake testen.
6. Client-/Protokolltests für Fehlerantworten, Timeouts und ungültige Payloads ergänzen.
7. Env-Beispiel und Kapitel 04/05/09/11 aktualisieren.

## Neuen Druckparameter hinzufügen

1. `PrintParameters` und Validierung in `printer/print_parameters.py` erweitern.
2. Logischen Wert eindeutig auf einen Slicer-Schlüssel abbilden; Profil-Read/Write testen.
3. `PARAMETER_DEFINITIONS` und Vollständigkeitsprüfung in `optimizer/config.py` anpassen.
4. `_numeric_parameters`, `_parameter_key` und Hardware-Konvertierung aktualisieren.
5. Plan-CSV, `CsvCycleRecorder` und Optimierer-CSV-Schema migrieren.
6. Beispielkonfigurationen und Parameter-/Bounds-Tests ändern.
7. Wissenschaftliche Einheit, Quantisierung und sichere Maschinenlimits dokumentieren.

Eine Schemaänderung darf vorhandene Laufverzeichnisse nicht stillschweigend umdeuten; gegebenenfalls Schema-Version erhöhen und Migration implementieren.

## Neue Optimierungsstrategie hinzufügen

1. Alias und erlaubte Optionen in `optimizer/config.py` ergänzen.
2. `StrategyAdapter.propose()` implementieren und über `build_strategy()` registrieren.
3. Nur normierte Werte über `ParameterSpace` verarbeiten.
4. Deterministische Seeds und vollständigen JSON-serialisierbaren Zustand speichern.
5. Batchgröße und vollständige Vorresultate validieren.
6. Duplikate nach Quantisierung verhindern.
7. Factory-, Reproduzierbarkeits-, Resume-, Grenz- und unvollständige-Batch-Tests ergänzen.

## Logging und Debugging

Alle Haupt-CLIs konfigurieren `INFO` mit Zeit, Level, Loggername und Meldung. Hardwareläufe schreiben zusätzlich `<output_directory>/logs/optimizer_hardware.log`. Für tiefere SJ-Protokolldiagnose existieren DEBUG-Meldungen für TX/RX in ASCII und Hex, aber kein CLI-Schalter. Für eine lokale Diagnose kann der Log-Level im kontrollierten Entwicklungszweig angehoben werden; keine seriellen Logs veröffentlichen, ohne sie auf sensible Betriebsdaten zu prüfen.

Wichtige Diagnoseartefakte:

- `run_state.json` für Gesamtstatus;
- `runs/run_NNNN.json` und `attempt_history/` für Übergänge;
- Preflight-Receipts in `logs/`;
- `optimizer_state/` für Vorschlagsreproduzierbarkeit;
- `hardware_cycles.csv` und Bilder für den physischen Ablauf.

## Erkennbare Codekonventionen

Der aktuelle Kern verwendet Typannotationen, `dataclass(frozen=True)`, kleine Adapterklassen, `pathlib.Path`, spezifische Exceptions und `unittest`. Atomare JSON-Schreibvorgänge verwenden temporäre Dateien, Flush, `fsync` und `os.replace`. Es gibt jedoch keine formal konfigurierte Style-/Lint-Regel. Bei Änderungen sollten bestehende Typen und 79–88-Zeichen-Zeilenstil beibehalten und alle betroffenen Tests ergänzt werden.

Weiter: [11 – API-Referenz](11_api_referenz.md)

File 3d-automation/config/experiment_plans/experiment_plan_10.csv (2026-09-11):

cycle_number | top_solid_layers | print_speed | extrusion_width | extrusion_multiplier | temperature | fan_speed
1 | 6 | 57 | 0.407 | 1.084 | 219 | 51
2 | 6 | 57 | 0.407 | 1.084 | 219 | 51
3 | 6 | 57 | 0.407 | 1.084 | 219 | 51
4 | 6 | 57 | 0.407 | 1.084 | 219 | 51
5 | 6 | 57 | 0.407 | 1.084 | 219 | 51
6 | 6 | 57 | 0.407 | 1.084 | 219 | 51
7 | 6 | 57 | 0.407 | 1.084 | 219 | 51
8 | 6 | 57 | 0.407 | 1.084 | 219 | 51
9 | 6 | 57 | 0.407 | 1.084 | 219 | 51
10 | 6 | 57 | 0.407 | 1.084 | 219 | 51
11 | 4 | 68 | 0.401 | 1.121 | 216 | 74
12 | 4 | 68 | 0.401 | 1.121 | 216 | 74
13 | 4 | 68 | 0.401 | 1.121 | 216 | 74
14 | 4 | 68 | 0.401 | 1.121 | 216 | 74
15 | 4 | 68 | 0.401 | 1.121 | 216 | 74
16 | 4 | 68 | 0.401 | 1.121 | 216 | 74
17 | 4 | 68 | 0.401 | 1.121 | 216 | 74
18 | 4 | 68 | 0.401 | 1.121 | 216 | 74
19 | 4 | 68 | 0.401 | 1.121 | 216 | 74
20 | 4 | 68 | 0.401 | 1.121 | 216 | 74
21 | 6 | 52 | 0.462 | 1.09 | 229 | 55
22 | 6 | 52 | 0.462 | 1.09 | 229 | 55
23 | 6 | 52 | 0.462 | 1.09 | 229 | 55
24 | 6 | 52 | 0.462 | 1.09 | 229 | 55
25 | 6 | 52 | 0.462 | 1.09 | 229 | 55
26 | 6 | 52 | 0.462 | 1.09 | 229 | 55
27 | 6 | 52 | 0.462 | 1.09 | 229 | 55
28 | 6 | 52 | 0.462 | 1.09 | 229 | 55
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

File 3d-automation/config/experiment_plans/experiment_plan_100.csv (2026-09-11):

cycle_number | top_solid_layers | print_speed | extrusion_width | extrusion_multiplier | temperature | fan_speed
1 | 8 | 79 | 0.404 | 1.151 | 225 | 60
2 | 8 | 64 | 0.407 | 1.06 | 222 | 66
3 | 5 | 83 | 0.392 | 1.124 | 220 | 78
4 | 9 | 84 | 0.454 | 1.091 | 231 | 64
5 | 7 | 68 | 0.494 | 1.136 | 232 | 75
6 | 8 | 69 | 0.448 | 1.177 | 224 | 50
7 | 7 | 57 | 0.499 | 1.106 | 222 | 79
8 | 8 | 90 | 0.387 | 1.197 | 231 | 78
9 | 6 | 89 | 0.415 | 1.058 | 223 | 51
10 | 6 | 65 | 0.427 | 1.193 | 229 | 66
11 | 7 | 85 | 0.432 | 1.057 | 231 | 68
12 | 8 | 80 | 0.396 | 1.115 | 229 | 59
13 | 8 | 81 | 0.424 | 1.114 | 227 | 48
14 | 7 | 71 | 0.404 | 1.086 | 234 | 75
15 | 8 | 67 | 0.398 | 1.145 | 215 | 57
16 | 4 | 81 | 0.458 | 1.107 | 235 | 35
17 | 8 | 67 | 0.431 | 1.069 | 228 | 62
18 | 7 | 76 | 0.456 | 1.164 | 234 | 49
19 | 7 | 77 | 0.459 | 1.088 | 216 | 36
20 | 6 | 63 | 0.409 | 1.178 | 228 | 56
21 | 6 | 79 | 0.446 | 1.077 | 222 | 47
22 | 5 | 81 | 0.383 | 1.137 | 219 | 37
23 | 5 | 76 | 0.497 | 1.13 | 218 | 43
24 | 5 | 70 | 0.466 | 1.183 | 231 | 69
25 | 9 | 71 | 0.464 | 1.066 | 217 | 48
26 | 7 | 51 | 0.442 | 1.112 | 226 | 69
27 | 8 | 52 | 0.481 | 1.111 | 223 | 56
28 | 5 | 88 | 0.424 | 1.189 | 220 | 35
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

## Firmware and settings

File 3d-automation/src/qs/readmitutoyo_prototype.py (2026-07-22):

from dataclasses import dataclass
import re
import time

import serial


SERIAL_PORT = "/dev/ttyUSB0"
BAUD_RATE = 38400
MEASUREMENT_TIMEOUT_SECONDS = 60


ERROR_MESSAGES = {
    "003": "Origin position was not reached in time.",
    "004": "Retraction position was not reached in time.",
    "005": "Origin limit remains active.",
    "006": "Retraction limit remains active.",
    "007": "Detector over-range.",
    "011": "Command sent while the device is busy.",
    "012": "Control timeout.",
    "013": "Communication buffer overflow.",
    "014": "Flash memory erase error.",
    "015": "Flash memory write error.",
    "016": "Program error.",
    "017": "System error.",
    "018": "Invalid measurement start position.",
    "019": "Invalid setting value.",
    "022": "Detector disconnected.",
    "030": "Illegal command.",
    "031": "Invalid command format.",
    "032": "Invalid command value.",
    "033": "Command is still being processed.",
    "071": "SPC communication error.",
    "101": "No calculation results available.",
    "102": "Calculated result is out of range.",
    "103": "Measurement interrupted because of result over-range.",
    "110": "Insufficient number of peaks and valleys.",
    "111": "Rz cannot be calculated: insufficient peaks and valleys.",
    "112": "Insufficient data points.",
    "113": "Invalid calculation region.",
    "114": "No profile element.",
    "115": "BAC/ADC calculation failed due to insufficient peaks and valleys.",
    "116": "Rk calculation failed.",
    "117": "R-Motif calculation failed: fewer than two valid local peaks.",
    "118": "R-Motif exceeds upper limit length A.",
    "121": "W-Motif calculation failed: fewer than three motifs.",
    "130": "Other calculation error.",
}


class SJ220Error(RuntimeError):
    """Base exception for errors related to the SJ-220."""


class SJ220DeviceError(SJ220Error):
    """Error reported directly by the SJ-220."""

    def __init__(
        self,
        code: str,
        command: str,
        error_byte: str | None = None,
    ):
        self.code = code
        self.command = command
        self.error_byte = error_byte

        description = ERROR_MESSAGES.get(
            code,
            "Unknown SJ-220 error.",
        )

        details = f"SJ-220 error {code}: {description}"

        if error_byte is not None:
            details += f" Error position/byte: {error_byte}."

        details += f" Command: {command}"

        super().__init__(details)


class SJ220ProtocolError(SJ220Error):
    """Unexpected or malformed response from the SJ-220."""


@dataclass(frozen=True)
class MeasurementResult:
    parameter: str
    value: float
    unit: str
    raw_value: str


def send_command(
    ser: serial.Serial,
    command: str,
) -> str:
    payload = f"{command}\r".encode("ascii")

    # Nicht vor jedem Befehl resetten.
    ser.write(payload)
    ser.flush()

    raw_response = ser.read_until(b"\r")

    print(f"TX: {payload!r}")
    print(f"RX: {raw_response!r}")
    print(f"RX HEX: {raw_response.hex(' ').upper()}")

    if not raw_response:
        raise TimeoutError(
            f"No response from SJ-220 for command: {command}"
        )

    response = raw_response.decode(
        "latin-1",
        errors="replace",
    ).rstrip("\r")

    if response.startswith("OK"):
        return response[2:]

    error_match = re.fullmatch(
        r"NG(\d{3})(?:,(\d{2}))?",
        response,
    )

    if error_match:
        raise SJ220DeviceError(
            code=error_match.group(1),
            command=command,
            error_byte=error_match.group(2),
        )

    raise SJ220ProtocolError(
        f"Unexpected response for {command}: {response!r}"
    )

def read_status(ser: serial.Serial) -> str:
    status = send_command(ser, "RDSTU00")

    status_messages = {
        "000": "Idle / ready",
        "001": "Measurement in progress",
        "002": "Detector returning",
        "003": "Detector retracting",
        "004": "Detector retracted",
        "005": "Detector outside the normal origin state",
    }

    description = status_messages.get(
        status,
        "Unknown status",
    )

    print(f"Status: {status} – {description}")
    print("-" * 50)

    return status


def wait_for_measurement_completion(
    ser: serial.Serial,
) -> None:
    initial_status = read_status(ser)

    if initial_status != "000":
        raise SJ220Error(
            f"SJ-220 is not ready before measurement. "
            f"Current status: {initial_status}"
        )

    print("Starting measurement...")
    send_command(ser, "CTSTA")

    deadline = time.monotonic() + MEASUREMENT_TIMEOUT_SECONDS
    measurement_was_active = False

    while time.monotonic() < deadline:
        time.sleep(0.5)

        status = read_status(ser)

        if status in {"001", "002"}:
            measurement_was_active = True
            continue

        if status == "000":
            if measurement_was_active:
                print("Movement completed.")
                return

            # Avoid treating an immediate idle response as a completed
            # measurement before the device has actually started.
            continue

        if status in {"003", "004", "005"}:
            raise SJ220Error(
                f"Unexpected detector status during measurement: {status}"
            )

    raise TimeoutError(
        f"Measurement did not finish within "
        f"{MEASUREMENT_TIMEOUT_SECONDS} seconds."
    )


def read_parameter_count(
    ser: serial.Serial,
) -> int:
    payload = send_command(ser, "RDPAR")

    if not re.fullmatch(r"\d{2}", payload):
        raise SJ220ProtocolError(
            f"Invalid RDPAR response payload: {payload!r}"
        )

    parameter_count = int(payload)

    if parameter_count <= 0:
        raise SJ220Error(
            "The SJ-220 reports that no parameters are configured."
        )

    print(f"Configured parameters: {parameter_count}")
    print("-" * 50)

    return parameter_count


def parse_result_payload(
    payload: str,
) -> MeasurementResult:
    """
    RDRES02 returns fixed-width fields:

    - parameter name: 6 characters
    - result:         7 characters
    - unit:           3 characters
    """
    expected_length = 16

    if len(payload) < expected_length:
        raise SJ220ProtocolError(
            "Measurement response is too short. "
            f"Expected at least {expected_length} characters, "
            f"received {len(payload)}: {payload!r}"
        )

    parameter = payload[0:6].strip()
    raw_value = payload[6:13].strip()
    unit = payload[13:16].strip()

    if not parameter:
        raise SJ220ProtocolError(
            f"Parameter name is missing: {payload!r}"
        )

    try:
        value = float(raw_value.replace(",", "."))
    except ValueError as error:
        raise SJ220ProtocolError(
            f"Measurement value is not numeric: "
            f"{raw_value!r}, full payload: {payload!r}"
        ) from error

    return MeasurementResult(
        parameter=parameter,
        value=value,
        unit=unit,
        raw_value=raw_value,
    )
RESULT_TIMEOUT_SECONDS = 10
RESULT_RETRY_INTERVAL_SECONDS = 0.25


def read_result_with_retry(
    ser: serial.Serial,
    parameter_index: int,
) -> MeasurementResult:
    command = f"RDRES02,{parameter_index:02d},00"
    deadline = time.monotonic() + RESULT_TIMEOUT_SECONDS

    while time.monotonic() < deadline:
        try:
            payload = send_command(ser, command)
            return parse_result_payload(payload)

        except SJ220DeviceError as error:
            # 101: Noch keine Berechnungsergebnisse vorhanden.
            # 033: Befehl wird noch verarbeitet.
            if error.code in {"101", "033"}:
                print(
                    f"Result not ready yet "
                    f"(SJ-220 error {error.code}). Retrying..."
                )
                time.sleep(RESULT_RETRY_INTERVAL_SECONDS)
                continue

            # Overrange und andere echte Messfehler sofort melden.
            raise

    raise TimeoutError(
        f"No calculation result became available within "
        f"{RESULT_TIMEOUT_SECONDS} seconds for parameter "
        f"{parameter_index}."
    )

def read_all_results(
    ser: serial.Serial,
) -> list[MeasurementResult]:
    parameter_count = read_parameter_count(ser)
    results: list[MeasurementResult] = []

    print("Reading calculation results...")

    # SJ-220 parameter numbering starts at 01, not 00.
    for parameter_number in range(1, parameter_count + 1):
        result = read_result_with_retry(
            ser,
            parameter_number,
        )

        results.append(result)

        print(
            f"Parameter {parameter_number:02d}: "
            f"{result.parameter} = "
            f"{result.value} {result.unit}"
        )
        print("-" * 50)

    return results


def print_required_results(
    results: list[MeasurementResult],
) -> None:
    results_by_name = {
        result.parameter.strip(): result
        for result in results
    }

    print("\nMeasurement results")
    print("=" * 50)

    for result in results:
        print(
            f"{result.parameter}: "
            f"{result.value} {result.unit}"
        )

    print("=" * 50)

    ra = results_by_name.get("Ra")
    rz = results_by_name.get("Rz")

    if ra is None:
        print("Warning: Ra is not configured on the SJ-220.")
    else:
        print(f"Ra = {ra.value} {ra.unit}")

    if rz is None:
        print("Warning: Rz is not configured on the SJ-220.")
    else:
        print(f"Rz = {rz.value} {rz.unit}")


def main() -> None:
    try:
        with serial.Serial(
        port=SERIAL_PORT,
        baudrate=38400,
        bytesize=serial.EIGHTBITS,
        parity=serial.PARITY_NONE,
        stopbits=serial.STOPBITS_ONE,
        timeout=3,
        write_timeout=3,
        rtscts=True,
        dsrdtr=False,
        xonxoff=False,
        ) as ser:
            ser.reset_input_buffer()
            ser.reset_output_buffer()
            wait_for_measurement_completion(ser)

            print("\nReading measurement results...")
            results = read_all_results(ser)

            print_required_results(results)

    except SJ220DeviceError as error:
        print("\nMEASUREMENT FAILED")
        print("=" * 50)
        print(error)

        if error.code in {"007", "102", "103"}:
            print(
                "Check the detector position, the workpiece alignment "
                "and the configured measurement range."
            )

    except SJ220ProtocolError as error:
        print("\nPROTOCOL ERROR")
        print(error)

    except TimeoutError as error:
        print("\nTIMEOUT")
        print(error)

    except serial.SerialException as error:
        print("\nSERIAL CONNECTION ERROR")
        print(error)

    except KeyboardInterrupt:
        print("\nProgram stopped by user.")


if __name__ == "__main__":
    main()

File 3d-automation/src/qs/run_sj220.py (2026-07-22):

from __future__ import annotations

import logging
import sys

from qs.sj220_exceptions import (
    SJ220ConnectionError,
    SJ220DeviceError,
    SJ220Error,
    SJ220PortInUseError,
    SJ220ProtocolError,
    SJ220ResultError,
    SJ220StateError,
    SJ220TimeoutError,
)
from qs.sj220_service import SJ220Service


DEVICE_ERROR_HINTS: dict[str, str] = {
    "007": (
        "Detektorposition, Werkstückposition und "
        "Messbereich prüfen."
    ),
    "018": (
        "Die Startposition des Detektors ist ungültig."
    ),
    "022": (
        "Prüfen, ob der Detektor korrekt angeschlossen ist."
    ),
    "030": (
        "Der gesendete Befehl ist für das SJ-220 ungültig."
    ),
    "031": (
        "Befehlsformat und abschließendes CR-Zeichen prüfen."
    ),
    "032": (
        "Mindestens ein übergebener Befehlswert ist ungültig."
    ),
    "071": (
        "SPC-Verbindung und eingestellten Ausgabemodus prüfen."
    ),
    "101": (
        "Für den angefragten Parameter existiert kein "
        "Berechnungsergebnis."
    ),
    "102": (
        "Das berechnete Ergebnis liegt außerhalb "
        "des zulässigen Bereichs."
    ),
    "103": (
        "Die Messung wurde aufgrund eines Overrange "
        "abgebrochen."
    ),
}


def main() -> int:
    logging.basicConfig(
        level=logging.INFO,
        format="%(asctime)s | %(levelname)s | %(message)s",
    )

    try:
        with SJ220Service(
            port="/dev/ttyUSB0",
            baudrate=38400,
        ) as quality_station:
            report = quality_station.measure(
                required_parameters=("Ra", "Rz"),
            )

        print("\nMessung erfolgreich")
        print("=" * 50)

        for result in report.results:
            print(
                f"{result.parameter}: "
                f"{result.value} {result.unit}"
            )

        print("-" * 50)
        print(
            f"Messdauer: "
            f"{report.duration_seconds:.2f} Sekunden"
        )

        result_values = report.as_dict()

        print(f"Ra für Orchestrator: {result_values['Ra']}")
        print(f"Rz für Orchestrator: {result_values['Rz']}")

        return 0

    except SJ220DeviceError as error:
        print("\nSJ-220 hat einen Gerätefehler gemeldet.")
        print(error)

        hint = DEVICE_ERROR_HINTS.get(error.code)

        if hint is not None:
            print(f"Hinweis: {hint}")

        return 2

    except SJ220PortInUseError as error:
        print("\nSchnittstelle wird bereits verwendet")
        print(error)
        print(
            "Beende den anderen SJ-220-Prozess, bevor du eine "
            "neue Messung startest."
        )
        return 3
    except SJ220ConnectionError as error:
        print("\nVerbindungsfehler")
        print(error)
        print(
            "Prüfe Kabel, Port, Berechtigungen und "
            "ob das SJ-220 eingeschaltet ist."
        )
        return 3

    except SJ220TimeoutError as error:
        print("\nSJ-220 antwortet nicht")
        print(error)
        print(
            "Der serielle Port konnte geöffnet werden, aber vom "
            "Messgerät kam keine vollständige Antwort."
        )
        print(
            "Prüfe, ob das SJ-220 eingeschaltet ist und ob das "
            "RS-232C-Kabel vollständig verbunden ist."
        )
        return 4

    except SJ220StateError as error:
        print("\nUngültiger Gerätezustand")
        print(error)
        return 5

    except SJ220ResultError as error:
        print("\nUngültiges oder unvollständiges Messergebnis")
        print(error)
        return 6

    except SJ220ProtocolError as error:
        print("\nProtokollfehler")
        print(error)
        return 7

    except SJ220Error as error:
        print("\nAllgemeiner SJ-220-Fehler")
        print(error)
        return 8

    except KeyboardInterrupt:
        print("\nProgramm wurde vom Benutzer abgebrochen.")
        return 130

    except Exception:
        logging.exception(
            "Unexpected error outside the SJ-220 error handling."
        )
        return 99


if __name__ == "__main__":
    sys.exit(main())

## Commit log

2026-05-04 feat: add PrusaSlicer CLI gcode generation prototype
    [3003.stl, teamugstl.stl]
2026-05-07 refactor: separate slicer and printer services
2026-05-07 feat: integrate PrusaLinkPy for printer communication (initial prototype, untested)
2026-06-05 feat: add print orchestration and impove PrusaLink Service
2026-07-02 "feat(robot): add initial printer pickup positions and test sequence"
    [Oberflächenmessung_Testkörper_MK1 (1).stl]
2026-07-14 fis(qs): improve SJ-220 status and error handling
    [run_sj220.py, sj220_exceptions.py, sj220_service.py]
2026-08-01 feat(printer): add configurable print parameters
2026-08-01 feat(experiments): add validated experiment plan loading
    [experiment_plan_20.csv]
2026-08-01 feat(printer): add cycle-specific slicing
2026-08-01 feat(printer): support cycle-specific G-code uploads
2026-08-01 feat(orchestrator): automate single print-measure cycles
2026-08-01 feat(printer): cool parts before robot handling
2026-08-01 feat(model): update surface measurement specimen
    [Oberflächenmessung_Testkörper_MK1 (1).stl]
2026-08-06 fix: handle failed surface measurements and reset SJ-220 error 007
    [sj220_service.py]
2026-08-12 fix: stabilize end-to-end cycle and robot handling
    [experiment_plan_20.csv]
2026-08-13 feat: integrate camera capture into print cycle
2026-08-13 fix: use default arm speed for printer break-off
2026-08-13 fix: set default camera controls
2026-08-15 fix: constrain experiment parameter ranges
    [experiment_plan_20.csv]
2026-08-15 fix: increase gripper opening torque
2026-08-15 feat: download camera images to local computer
2026-08-22 feat(results): record clickable camera image paths
2026-08-22 feat(robot): increase printer pickup movement speed
2026-08-22 feat(experiments): support resumable 100-cycle runs
    [experiment_plan_100.csv]
2026-08-27 feat: add rounded test body as default model
    [15x15_V2_rounded.stl]
2026-08-30 Integrate configurable optimization framework
2026-09-03 docs: add system documentation and hardware optimizer configs
    [hardware_cycles.csv, results.csv]
2026-09-08 feat: improve experiment handling, objective configuration, print-time tracking, dependencies, and documentation
2026-09-08 feat: add configurable objectives, print-time tracking, resume handling, documentation, and strategy JSON configs
2026-09-11 Changes from before 11.SEP without merge and gripper change
    [experiment_plan_10.csv, experiment_plan_100.csv, experiment_plan_10x10_neu.csv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]
